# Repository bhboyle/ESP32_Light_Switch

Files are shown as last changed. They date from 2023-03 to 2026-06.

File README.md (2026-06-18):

## Ideas
I was thinking it might be a good idea to add the ability to backup and restore configurations. I hope to not have to replace these devices often but if you do have to it would be nice to have a backup of the configuration and just restore that to a new device. So I think I will make this the next feature I add to the firmware.

I have added the ability to export the switches configuration. Please note, the passwords like wifi and MQTT passwords are in plain text. This is not a problem for me but you may be concerned about this. I may work on encrypting them in the future but for now they will be in plain text. The import of the config file still needs to be coded.

## Issues
I have now ordered version three of the power board. It uses a CSE7759 energy metering chip that uses a 1 milli-ohm shunt resistor to measure the current flowing through the switch. I will have to modify the current monitoring code fairly heavily for the new energy metering to work. More to come... 

Version 3 of the power board DOES NOT WORK. Well more accurately the energy metering does not work. Do not use it. It blows components all over the place. Now on to version 4...

Almost done version 4 of the power board. I will be ordering them shortly and test them.

## Introduction
This project is an open source ESP32 based Wifi MQTT light switch. The device fits into a "Decor" style switch box. Sonoff devices are interesting but they do not fit into a regular box along side other non-smart switches.

I have gone through the first iteration of the design that does not include current sensing on the output. This version would work fine as a single on off switch but I would like this switch design to work for both single on/off switches and for three way switches as well. This requires current sensing that will be explained later.

## Objective
My objective for this project was explained at a high level in the introduction section but that does not explain my motivation for this project. Several years ago I had installed several TP-link smart switches in my home. All within a month of each other. Five years later they all died within a month of each other. That seemed like too much of a coincidence to me so I decided to make my own. This project is the idea come to life.

## Features
I will use an integrated web server for manage the following features
 * Web based control of the switch
 * Web based status of switch
 * Web based OTA updates of the switch firmware
 * Web based settings update
 * Stand alone AP mode for initial configuration
 * Remember power state for power failures using preferences lib
 * LED colors. Red = Boot up, Yellow = WIFI connected, Green = WIFI and MQTT connected, Blue = AP is active.
 * Fits into a standard wall box in North America as a Decor style switch
 * 3D models for 3D printing the housing for the parts
 * Links to the schematic and PCB designs for easy board ordering
 * LED Indication of relay status. "Breathing" LED means relay is off. Solid LED means Relay is on.
 * MQTT control of the switch
 * MQTT status of switch

## Design
At the heart of the project are two custom designed PCBs. There is a power board that handles the SPDT relay for AC switching, the conversion of the AC in to DC and provides both 5 volts DC and 3.3 volts DC to the controller board. The controller board has the ESP32 for control, communications and the buttons for triggering. There is a "light" button and a "factory" button. The light button is of course used to turn the light on and off while the factory button is used to do a factory reset. There is a Neopixel on the control board to indicate the status of the device in addition to a dedicated power led. [Here is a link](https://oshwlab.com/bhboyle/esp32-light-switch) to the EasyEDA project. This link will give you access to the schematics and board layouts. From there you can directly order boards from JLCPCB.

For safety and simplicity sake, I used the [Mean Well IRM-02-5](https://www.digikey.ca/en/products/detail/mean-well-usa-inc/IRM-02-5/7704628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) 2 watt AC-DC converter. As with most things it is a compromise. In this case between simplicity, size, safety and cost. It is a little on the pricy side at $10 USD each but it makes it very simple to build the power supply and because it is a sealed housing it is nice and safe. This module creates 5 volts DC that drives the relay and the Neopixel. In addition to the 5V power supply, I use an LDO linear regulator to generate the 3.3 volts the ESP32 needs to operate.

### The PCBs
I have designed the boards in EasyEDA. Because if this ordering from JLCPCB is very easy. I have JLCPCB populate the boards. For the power/switching board I have them populate the back of the board which is all SMB components. the front side of the board has the power supply, relay, power connection terminals and the current monitor. They all have to be manually soldered. There are also a few discrete SMB components that have to be manually soldered. The control board I ordered fully populated except for the board to board connector because I prefer to manually solder it myself. 

In order to use this as a three way switch and have the device be aware of whether or not the lighting circuit is live or not you need to measure the current flowing through the lighting circuit. This is required because it is possible, in a three way circuit for the circuit to be live without the SPDT relay being engaged due to the nature of three way circuits. Anyone who has used an three light switch knows that the two switches can end up in any position. Because of this, I use a Hall effect current sensor to determine if the lighting circuit is live or not. This has the added benefit of being able to determine how much power the circuit is using over time. Code for this part of the project is still being worked on.

I have updated the power supply board to include a LC filter on the 3.3 volt line. I have not tested this yet and it yet but it is a standard LC filter and I used a LC simulator to get near -80DB on all noise so it should work just fine. I have included an indicator to the schematic if you want to remove the filter from the circuit.

## Programming
Programming the device the first time has to be done via the USB C connector before the device is assembled. Once the initial programming is done the device can be programmed via the web interface by going to the following URL: http://deviceIp/update From here you can upload the firmware generated from platformIO.

## Todo
* The biggest remaining item on the list of things to do at this point is documentation and code optimization. 

### Parts List
[Here is a file](https://docs.google.com/spreadsheets/d/1vnkWm73apcbOtNqYmAgQMh_5zk3PtoovNklXcG1IaSc/edit?usp=sharing) that has links to the most of the harder to find parts or just parts that you have to solder yourself. 

### Software Build environment
Just in case it is not obvious, I wanted to mention that the project is being worked on in VScode with the PlatformIO plugin. If you choose to compile the code in the Arduino IDE you simply need to get the main.cpp file from the SRC folder and put it in to your sketch folder. You will also need to gather and install the needed libraries.

### DISCLAMER
Please understand that this project uses mains power and if you do not know what you're doing you can seriously harm or even kill yourself. In some places you may not even be legally allowed to install electrical equipment if you are not a licensed electrician. PLEASE be careful and if you are not confident do not do electrical work yourself. **You have been warned**

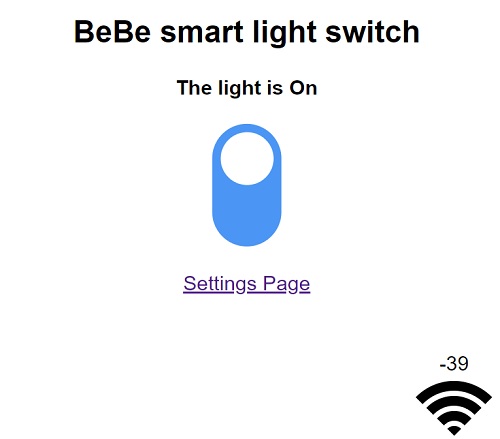
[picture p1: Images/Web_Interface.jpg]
web Image
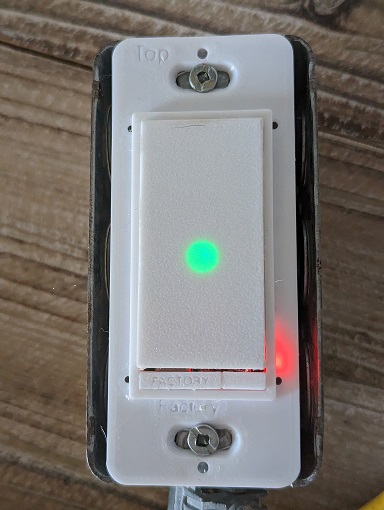
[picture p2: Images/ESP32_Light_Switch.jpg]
first image
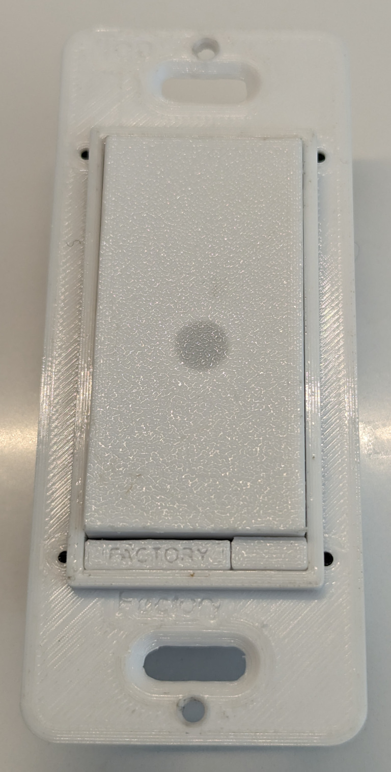
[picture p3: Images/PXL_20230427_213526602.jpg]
Second image
  
## Problems
Still having issues with the power on detection for three way mode. I have looked it how Sonoff devices do this but I dont think that will work for me here. If you have ideas how to do this please let me know.

## Ideas
I was thinking it might be a good idea to add the ability to backup and restore configurations. I hope to not have to replace these devices often but if you do have to it would be nice to have a backup of the configuration and just restore that to a new device. So I think I will make this the next feature I add to the firmware.

I have added the ability to export the switches configuration. Please note, the passwords like wifi and MQTT passwords are in plain text. This is not a problem for me but you may be concerned about this. I may work on encrypting them in the future but for now they will be in plain text. The import of the config file still needs to be coded.

## Issues
I have now ordered version three of the power board. It uses a CSE7759 energy metering chip that uses a 1 milli-ohm shunt resistor to measure the current flowing through the switch. I will have to modify the current monitoring code fairly heavily for the new energy metering to work. More to come... 

Version 3 of the power board DOES NOT WORK. Well more accurately the energy metering does not work. Do not use it. It blows components all over the place. Now on to version 4...

Almost done version 4 of the power board. I will be ordering them shortly and test them.

## Introduction
This project is an open source ESP32 based Wifi MQTT light switch. The device fits into a "Decor" style switch box. Sonoff devices are interesting but they do not fit into a regular box along side other non-smart switches.

I have gone through the first iteration of the design that does not include current sensing on the output. This version would work fine as a single on off switch but I would like this switch design to work for both single on/off switches and for three way switches as well. This requires current sensing that will be explained later.

## Objective
My objective for this project was explained at a high level in the introduction section but that does not explain my motivation for this project. Several years ago I had installed several TP-link smart switches in my home. All within a month of each other. Five years later they all died within a month of each other. That seemed like too much of a coincidence to me so I decided to make my own. This project is the idea come to life.

## Features
I will use an integrated web server for manage the following features
 * Web based control of the switch
 * Web based status of switch
 * Web based OTA updates of the switch firmware
 * Web based settings update
 * Stand alone AP mode for initial configuration
 * Remember power state for power failures using preferences lib
 * LED colors. Red = Boot up, Yellow = WIFI connected, Green = WIFI and MQTT connected, Blue = AP is active.
 * Fits into a standard wall box in North America as a Decor style switch
 * 3D models for 3D printing the housing for the parts
 * Links to the schematic and PCB designs for easy board ordering
 * LED Indication of relay status. "Breathing" LED means relay is off. Solid LED means Relay is on.
 * MQTT control of the switch
 * MQTT status of switch

## Design
At the heart of the project are two custom designed PCBs. There is a power board that handles the SPDT relay for AC switching, the conversion of the AC in to DC and provides both 5 volts DC and 3.3 volts DC to the controller board. The controller board has the ESP32 for control, communications and the buttons for triggering. There is a "light" button and a "factory" button. The light button is of course used to turn the light on and off while the factory button is used to do a factory reset. There is a Neopixel on the control board to indicate the status of the device in addition to a dedicated power led. [Here is a link](https://oshwlab.com/bhboyle/esp32-light-switch) to the EasyEDA project. This link will give you access to the schematics and board layouts. From there you can directly order boards from JLCPCB.

For safety and simplicity sake, I used the [Mean Well IRM-02-5](https://www.digikey.ca/en/products/detail/mean-well-usa-inc/IRM-02-5/7704628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) 2 watt AC-DC converter. As with most things it is a compromise. In this case between simplicity, size, safety and cost. It is a little on the pricy side at $10 USD each but it makes it very simple to build the power supply and because it is a sealed housing it is nice and safe. This module creates 5 volts DC that drives the relay and the Neopixel. In addition to the 5V power supply, I use an LDO linear regulator to generate the 3.3 volts the ESP32 needs to operate.

### The PCBs
I have designed the boards in EasyEDA. Because if this ordering from JLCPCB is very easy. I have JLCPCB populate the boards. For the power/switching board I have them populate the back of the board which is all SMB components. the front side of the board has the power supply, relay, power connection terminals and the current monitor. They all have to be manually soldered. There are also a few discrete SMB components that have to be manually soldered. The control board I ordered fully populated except for the board to board connector because I prefer to manually solder it myself. 

In order to use this as a three way switch and have the device be aware of whether or not the lighting circuit is live or not you need to measure the current flowing through the lighting circuit. This is required because it is possible, in a three way circuit for the circuit to be live without the SPDT relay being engaged due to the nature of three way circuits. Anyone who has used an three light switch knows that the two switches can end up in any position. Because of this, I use a Hall effect current sensor to determine if the lighting circuit is live or not. This has the added benefit of being able to determine how much power the circuit is using over time. Code for this part of the project is still being worked on.

I have updated the power supply board to include a LC filter on the 3.3 volt line. I have not tested this yet and it yet but it is a standard LC filter and I used a LC simulator to get near -80DB on all noise so it should work just fine. I have included an indicator to the schematic if you want to remove the filter from the circuit.

## Programming
Programming the device the first time has to be done via the USB C connector before the device is assembled. Once the initial programming is done the device can be programmed via the web interface by going to the following URL: http://deviceIp/update From here you can upload the firmware generated from platformIO.

## Todo
* The biggest remaining item on the list of things to do at this point is documentation and code optimization. 

### Parts List
[Here is a file](https://docs.google.com/spreadsheets/d/1vnkWm73apcbOtNqYmAgQMh_5zk3PtoovNklXcG1IaSc/edit?usp=sharing) that has links to the most of the harder to find parts or just parts that you have to solder yourself. 

### Software Build environment
Just in case it is not obvious, I wanted to mention that the project is being worked on in VScode with the PlatformIO plugin. If you choose to compile the code in the Arduino IDE you simply need to get the main.cpp file from the SRC folder and put it in to your sketch folder. You will also need to gather and install the needed libraries.

### DISCLAMER
Please understand that this project uses mains power and if you do not know what you're doing you can seriously harm or even kill yourself. In some places you may not even be legally allowed to install electrical equipment if you are not a licensed electrician. PLEASE be careful and if you are not confident do not do electrical work yourself. **You have been warned**

web Image first image Second image

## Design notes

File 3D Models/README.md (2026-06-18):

# Using the file

The file here is a Fusion 360 file. You will need to install and activate Fusion 360 to work with the model. 

The one file contains all of the individual bodies for the first version of the housing and buttons. I usually hide the item that I don't want to print and then use Fusion to send the file to Cura for 3D printing.

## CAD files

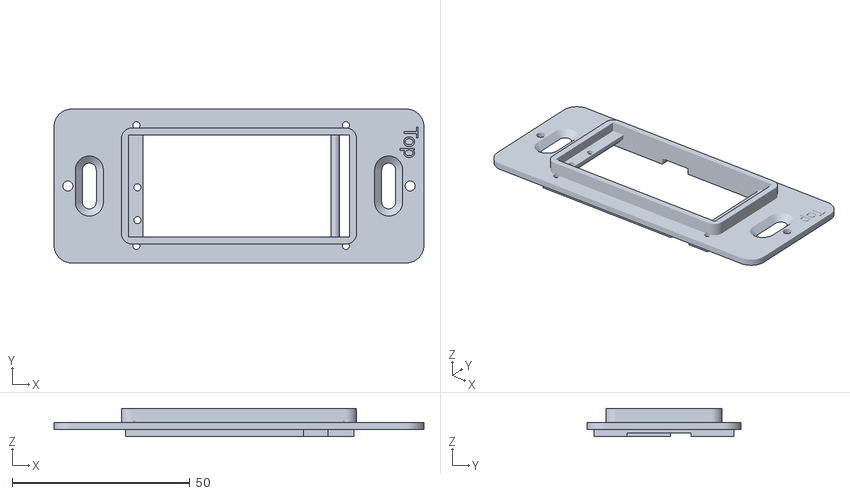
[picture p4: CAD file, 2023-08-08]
3D Models/V2 Face plate.stl
104.2 x 43.4 x 8.00

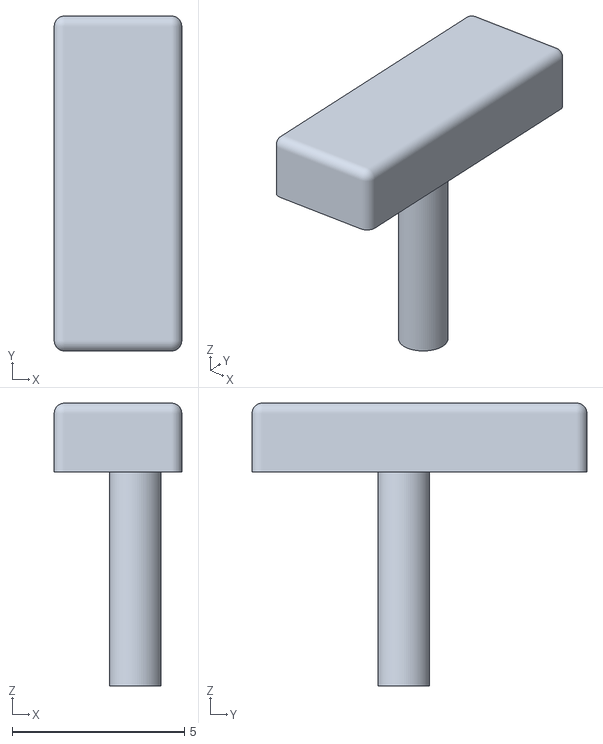
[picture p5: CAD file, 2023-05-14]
3D Models/V2 Reset Button.stl
3.70 x 9.71 x 8.20

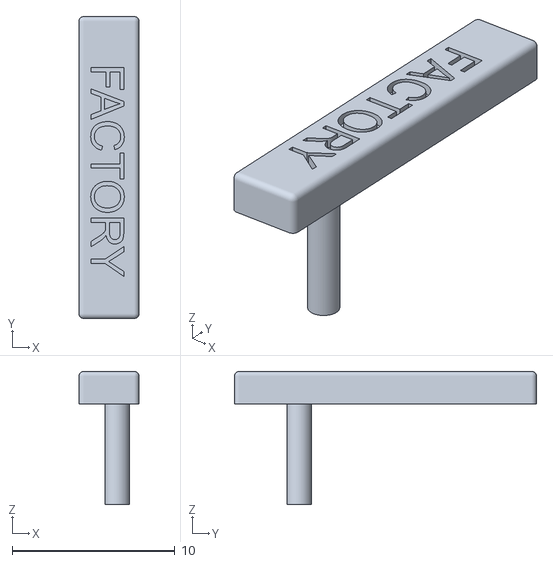
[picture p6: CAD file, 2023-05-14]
3D Models/V2 Factory Button.stl
3.70 x 18.6 x 8.20

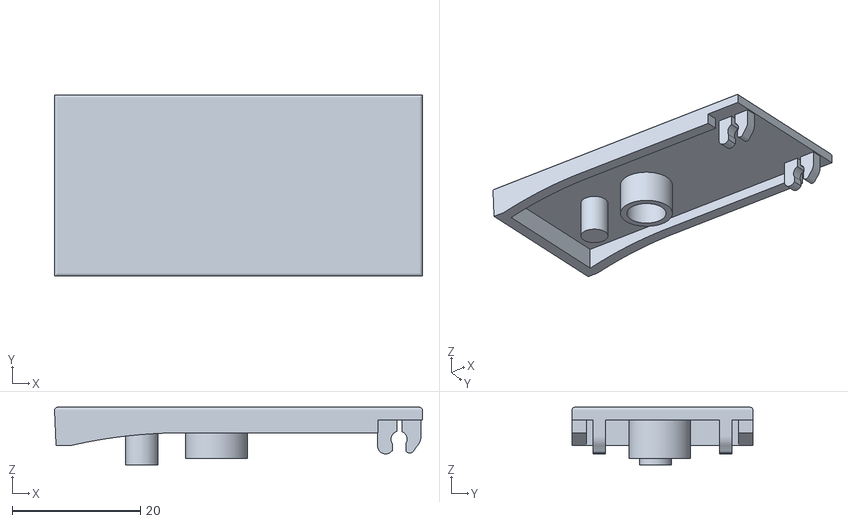
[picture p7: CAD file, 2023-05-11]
3D Models/V2 Light Button.stl
57.4 x 28.3 x 9.00

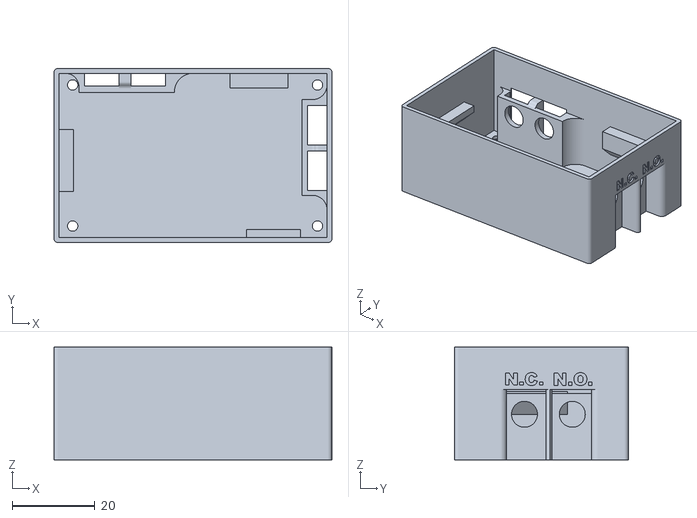
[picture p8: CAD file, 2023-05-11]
3D Models/V2 Lower Housing.stl
67.0 x 42.0 x 27.2

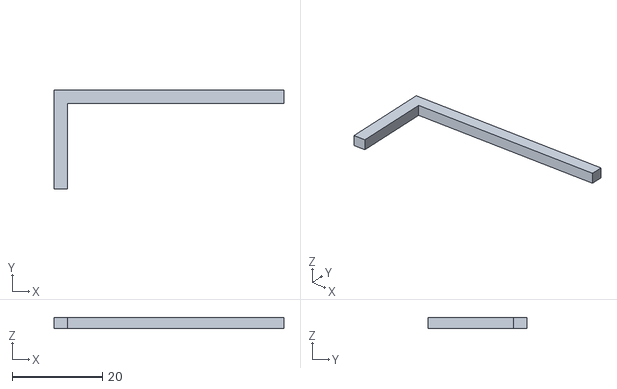
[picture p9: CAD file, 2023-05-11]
3D Models/V 2Spacer.stl
51.0 x 22.0 x 2.50

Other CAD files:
3D Models/ESP32 Light switch housing v41.f3d
3D Models/Left middle front corner.f3d

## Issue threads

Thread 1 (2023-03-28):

Need to add code to handle power monitoring

bhboyle, 2023-03-28:
I have added the ACS712 to the design. I need to add code to check if there is current andif there is then 1. report that, 2. log it power usage

bhboyle, 2023-04-03:
Code is in place but I need to get the updated boards to test the code

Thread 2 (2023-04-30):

Quiescent power draw

brusshamilton, 2023-04-30:
It looks like the quiescent power usage is around 2W for this design. Given modern lightbulbs use ~9W, that seems like a lot to devote to a switch.

Fortunately, I think there are some things we can optimize with this design.

The processor should probably be put into a low power mode between requests. That may be a bit difficult with WIFI. I'd have to check the datasheet in detail to so how much we can save here.

The hall effect sensor is a real power hog though. Have you considered making it so it can be disabled and enabled? We don't need to measure that all the time, so we should disable it when it's not in use.

Using an linear regulator to step down from 5V to 3.3V almost doubles the quiescent power usage. If we could get rid of the 5V requirement then that would be ideal. Otherwise we might want to bite the bullet and get a buck converter -- the 240mA draw from the ESP32 is not cheap.

bhboyle, 2023-04-30:
Hi. Thanks for taking the time to comment.

Given that the relay and the current montor are rated for 10 amps at 120 volts, that is 1200 watts of capacity. 2 watts in that scope is negligable. Also since my objective with this project was to have an ESP32 powered wifi based decor style light switch, I had to account for the highest power that the ESP32 and the rest of the circuit would need when selecting the power supply. My electronics class teacher always said that you should always supply double the curcuits power requierments. With that in mind I did not do as my teacher suggested in this case as the power supply does not provide 2*250ma plus the 90 ma the relay requires plus the other parts.

I feel that I made a decent comprmise on power supply versus power needs. Regardless of that there is always room for improvement but I am not willing to give up the ESP32 and the relay and just those two compoents use around 200ma or 2 watts at full power draw.

I could think about powering down the current sensor however the typical current draw is 8.5ma. This is less than the LED so I dont feel that it is worth considering.

Cheers.

brusshamilton, 2023-05-01:
That's interesting. I thought this was for a light switch so I did not consider that it might be asked to draw a full 10 amp load. Also, I guess my only experience with the Hall effect sensors is with small battery powered devices which have tighter power margins, so it doesn't seem to be a problem here. The relay is also only drawing the current when the switch is on (which I wouldn't consider quiescent) and only takes 200mW (based on the datasheet I pulled up for HF33F).

But you can still reduce the power usage if you can get rid of the 5V power rail. I thought you might need it for the relay, but the relay seems to support voltages that low. With a linear power regulator you're paying for the power at the higher voltage even if you only need the lower voltage. That's fine if you are not pulling much current, but at 250mA, going from 5V to 3.3V wastes 425mW as heat, compared to the 825mW that's performing useful work. I didn't see anywhere where you needed 5V other than USB, which can provide it's own 5V power. It should be safe to let that float at 3.3V when the 5V is not connected (for debugging/programming).

Also most IoT and other embedded devices take significant advantage of sleeping during idle times to reduce power usage (and heat generation, which can fatigue and prematurely age components).

As for the power supply margin, I think doubling might be useful for students, but typically I wouldn't overspec by more than 30%. You have the appropriate decoupling capacitors in the right places, so I'm not that concerned with power noise. Though as with all high frequency circuits you would want to check and if it is a problem see if you can run the system at 3.5 with a linear regulator down to 3.3 V for extra stability.

bhboyle, 2023-05-02:
The Neopixel and the relay both run on 5V. I had originally planned to use a 3.3v power supply and had looked at running the relay at 3.3v but once I decided to incorperate the Neopixel I went with the 5V and 3.3. LDO reg. I did a lot if bench testing the ESP32 and other 3.3v components and found that the ESP32 rarely drew more than around 80-100ma and when it did it was not for very long. With that said the current draw on the 3.3v reg averages around 100ma and the regulator never even get much more than warm. I would think the temp rise above ambiant is around the 5 degrees C range. someting I was very comfortable. If it was any more than that I would have redesign the power section.

I do see that what you mean about power saving modes for the ESP32 howver since I want the web page and the MQTT client active at all times I dont see how that could work in my use case.

Cheers.

Closed 2023-05-10.

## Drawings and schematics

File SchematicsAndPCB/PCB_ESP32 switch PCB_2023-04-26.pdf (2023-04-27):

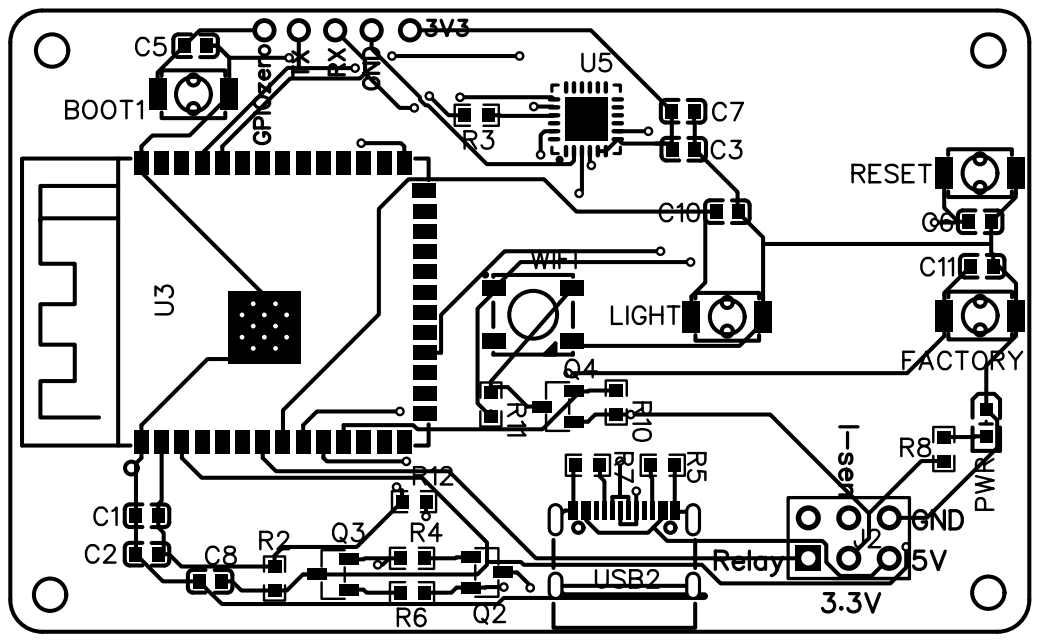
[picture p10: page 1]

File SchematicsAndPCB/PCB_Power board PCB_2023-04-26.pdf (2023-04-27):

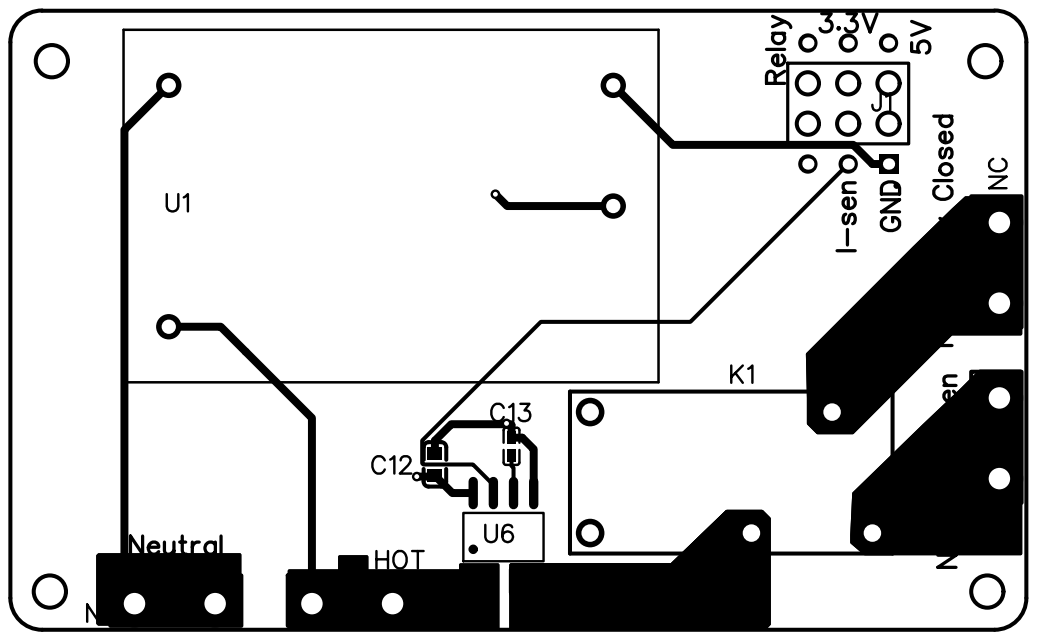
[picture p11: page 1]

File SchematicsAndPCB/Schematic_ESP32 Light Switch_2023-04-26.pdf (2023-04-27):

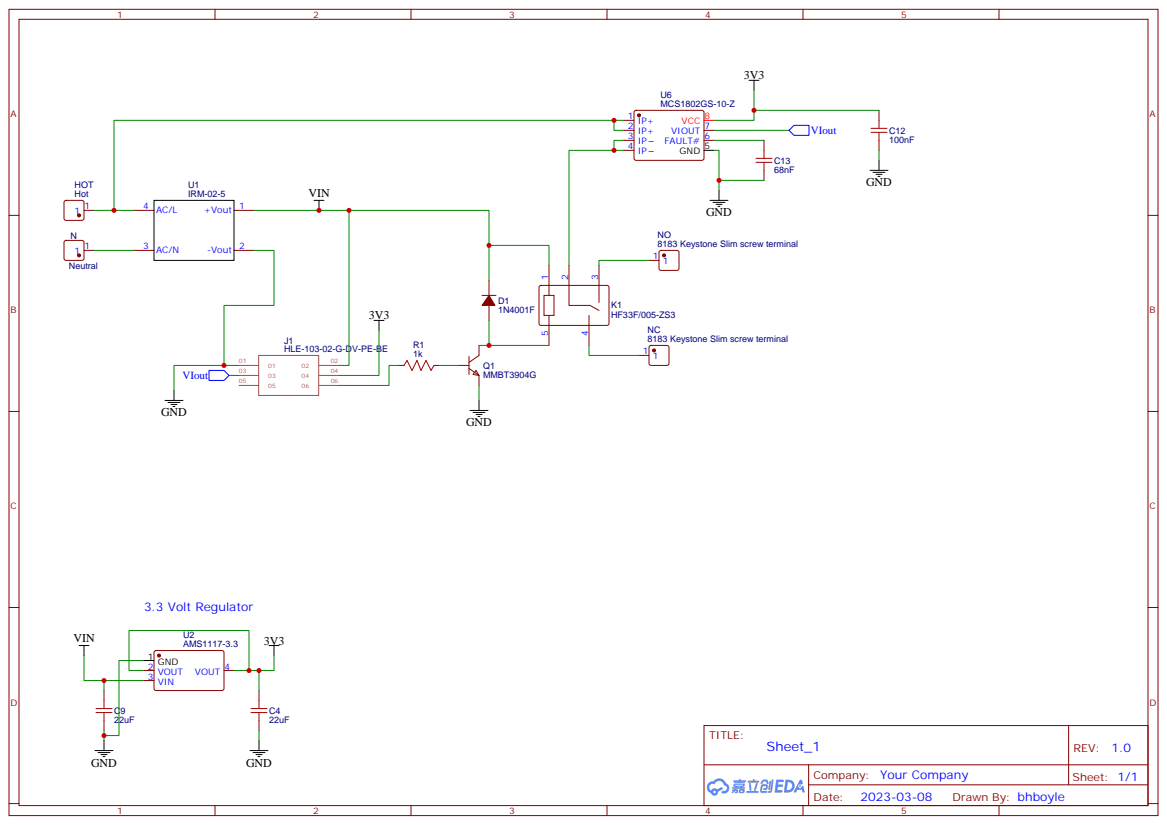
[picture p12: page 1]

HLE-103-02-G-DV-PE-BE

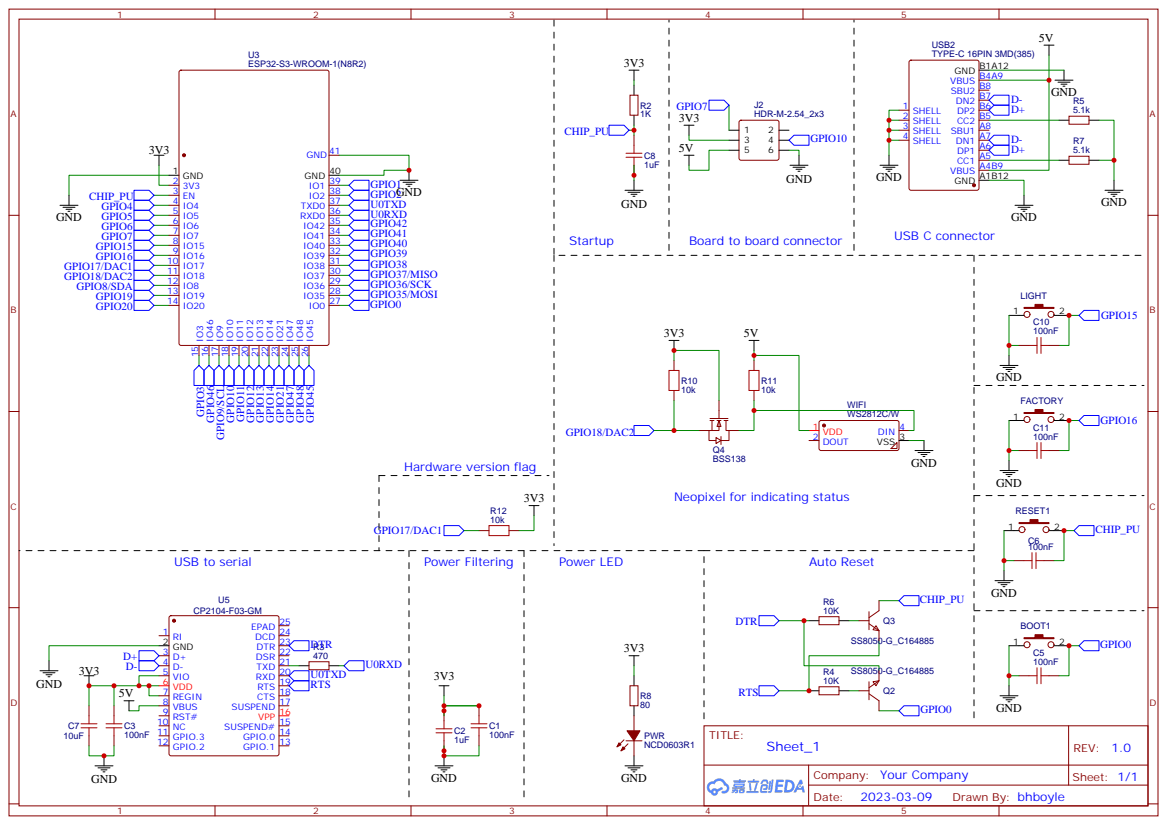
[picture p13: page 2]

IO0 27 IO⁴⁵ 26 IO⁴⁸ 25 IO⁴⁷ 24 IO²¹ 23 IO¹⁴ 22 IO¹³ 21 IO¹² 20 IO¹¹ 19 IO¹⁰ 18 IO⁹ 17 IO⁴⁶ 16 IO³ 15

Neopixel for indicating status

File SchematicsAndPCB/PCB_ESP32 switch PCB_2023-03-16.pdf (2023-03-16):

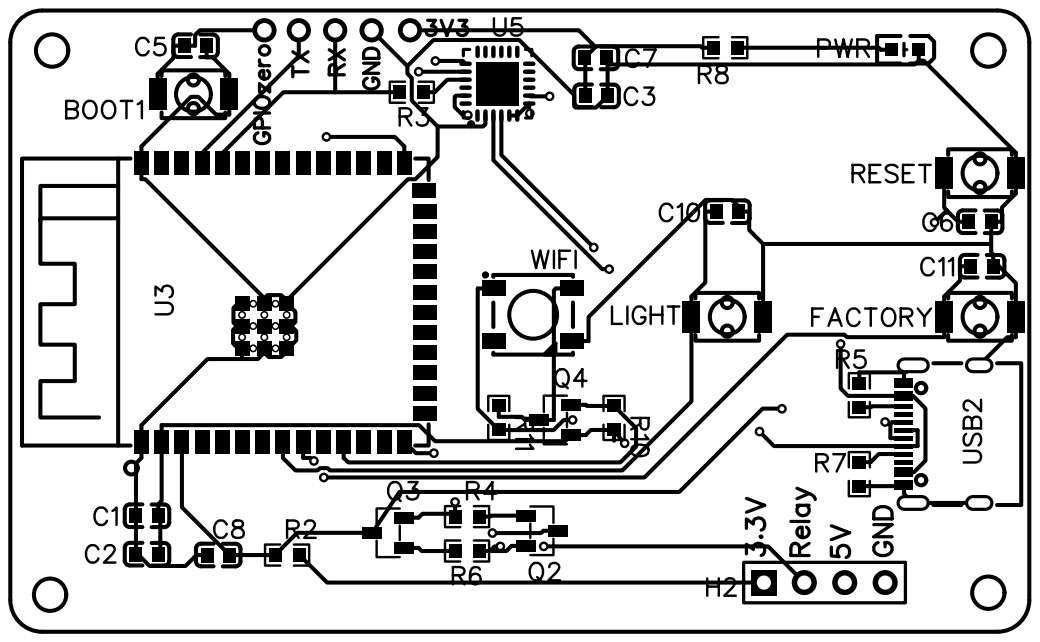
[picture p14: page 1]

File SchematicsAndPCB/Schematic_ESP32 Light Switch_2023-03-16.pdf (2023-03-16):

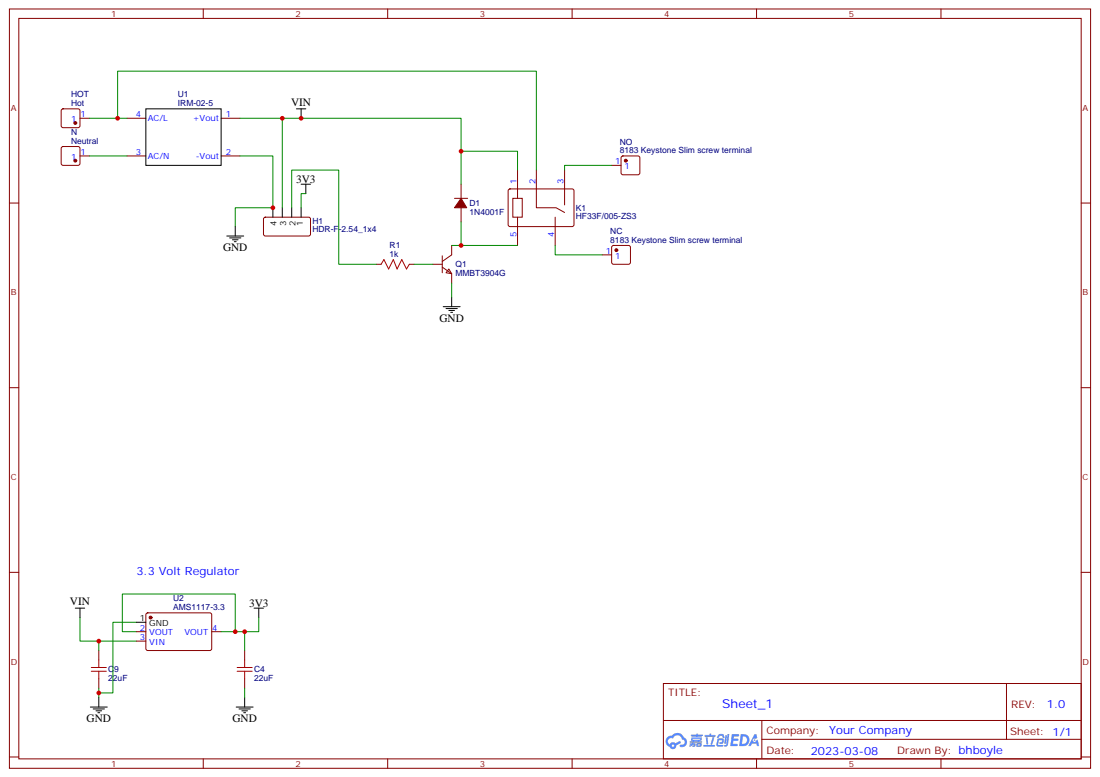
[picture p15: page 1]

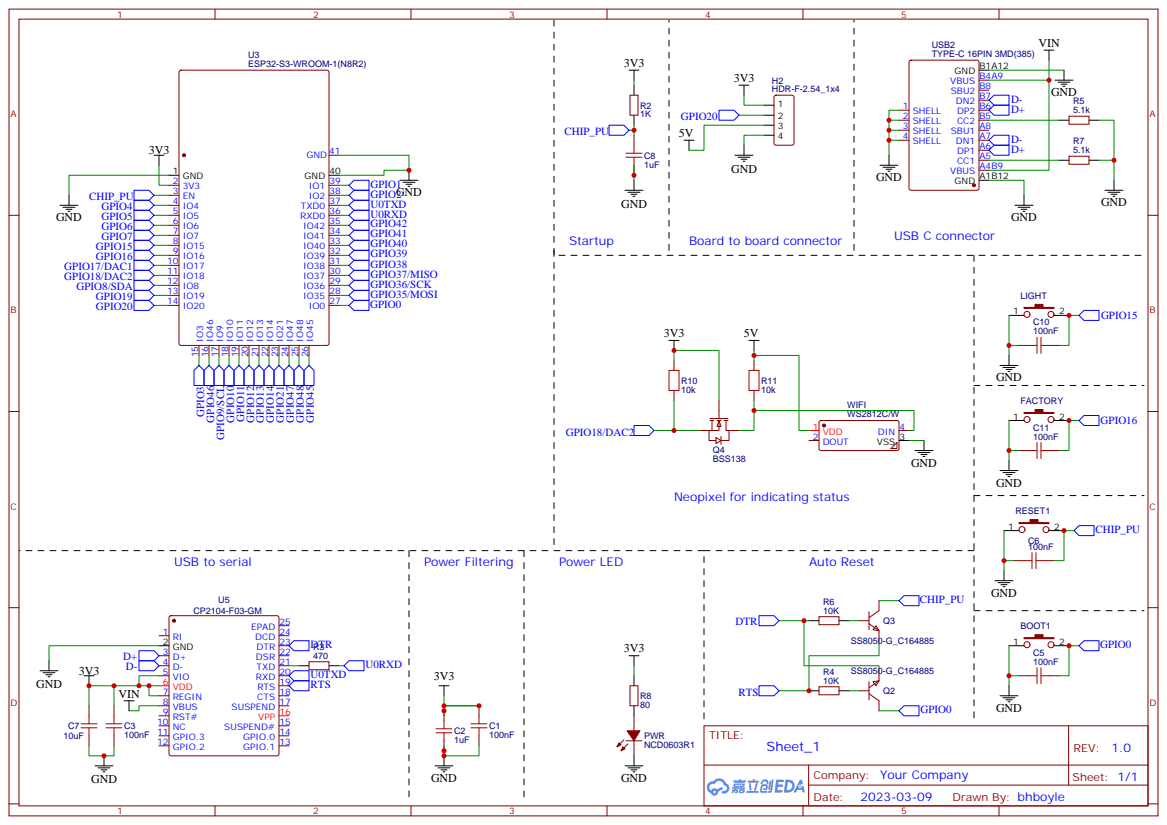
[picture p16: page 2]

IO0 27 IO⁴⁵ 26 IO⁴⁸ 25 IO⁴⁷ 24 IO²¹ 23 IO¹⁴ 22 IO¹³ 21 IO¹² 20 IO¹¹ 19 IO¹⁰ 18 IO⁹ 17 IO⁴⁶ 16 IO³ 15

Neopixel for indicating status

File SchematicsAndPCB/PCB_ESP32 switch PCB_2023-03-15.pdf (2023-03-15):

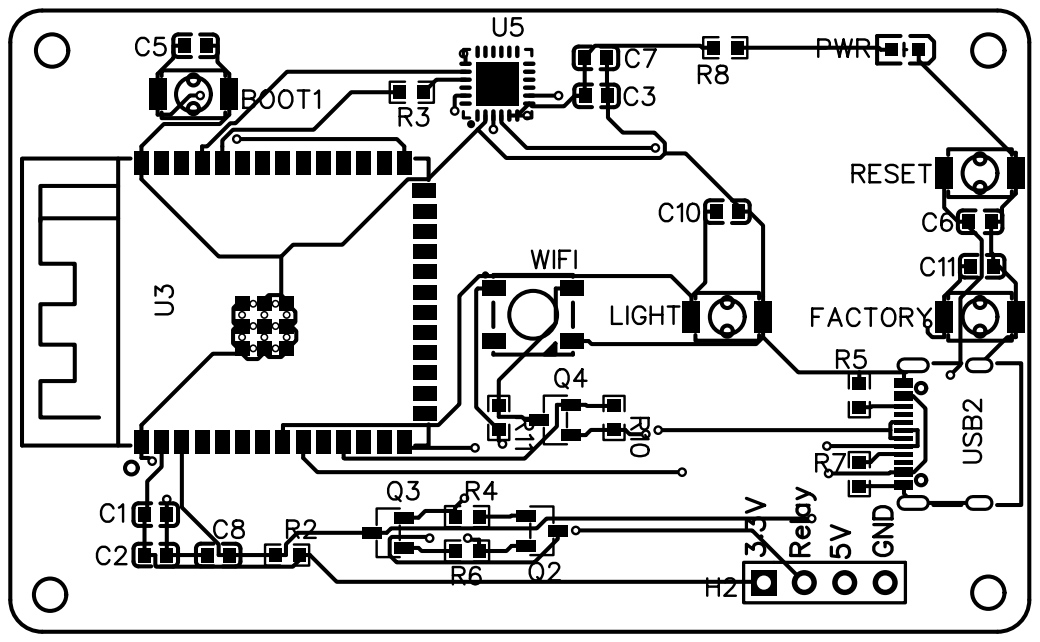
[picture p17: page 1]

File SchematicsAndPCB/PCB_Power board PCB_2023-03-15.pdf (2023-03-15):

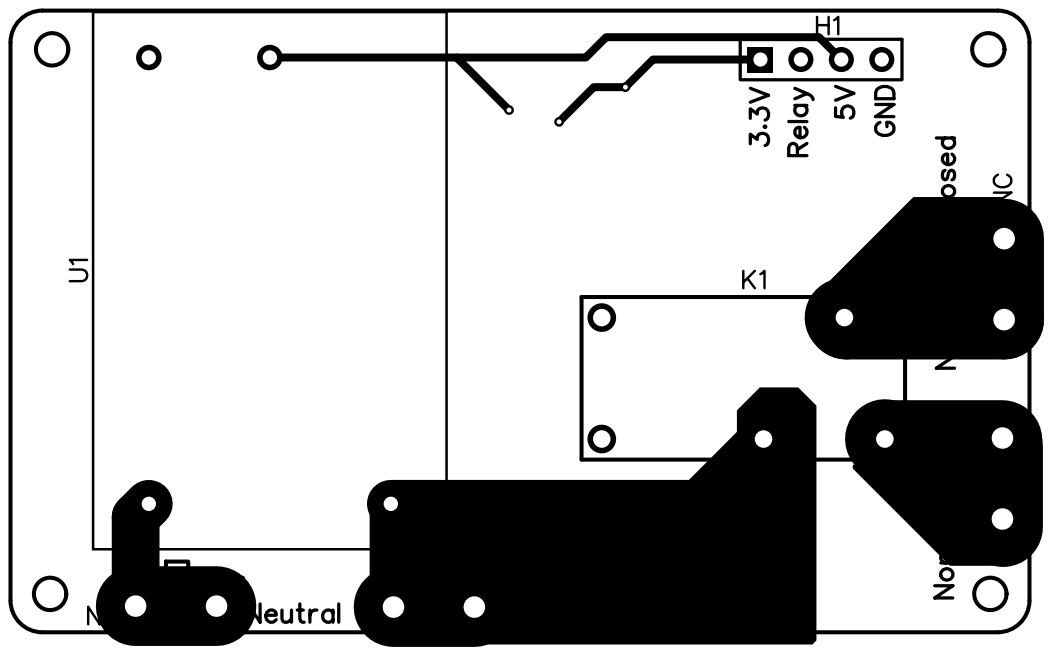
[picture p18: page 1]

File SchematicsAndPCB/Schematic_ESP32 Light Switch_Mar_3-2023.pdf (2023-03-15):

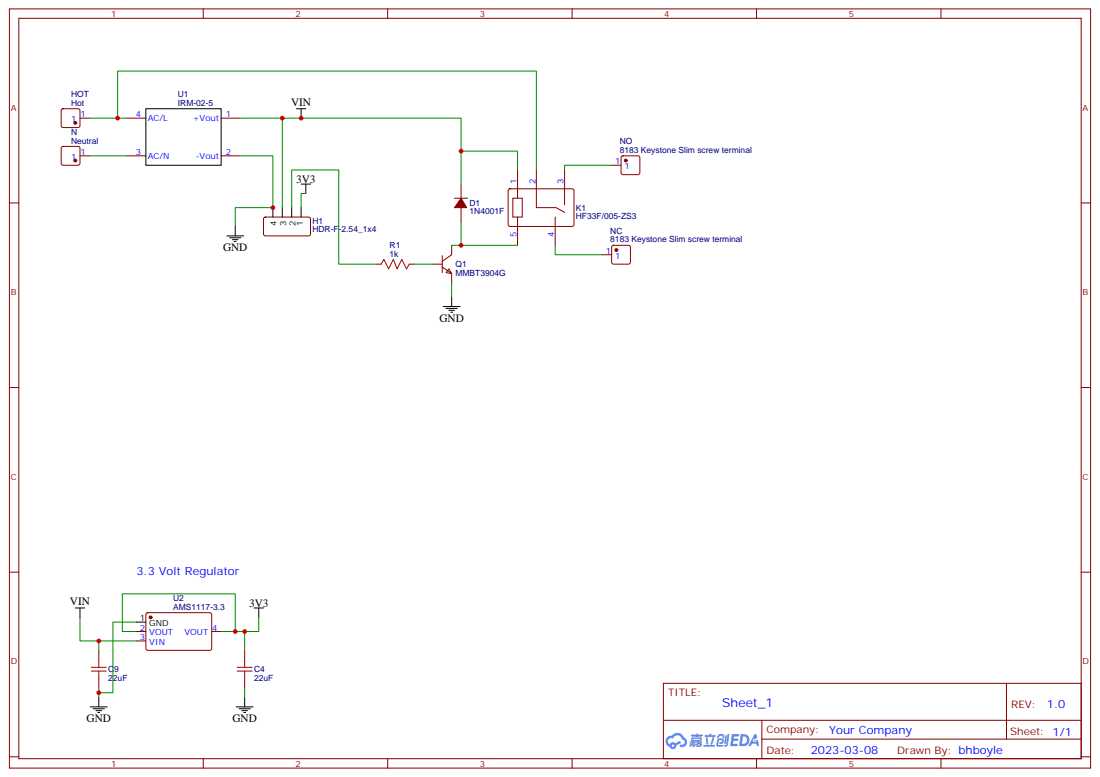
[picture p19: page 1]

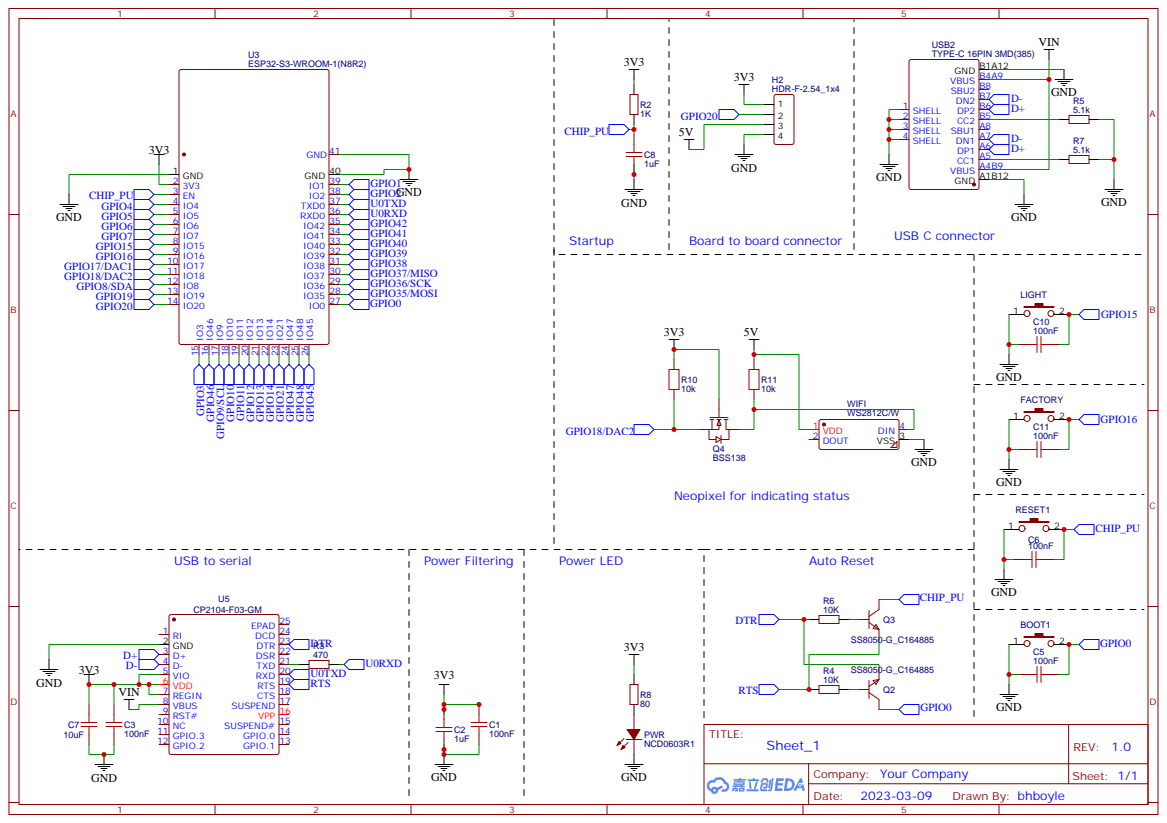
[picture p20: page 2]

IO0 27 IO⁴⁵ 26 IO⁴⁸ 25 IO⁴⁷ 24 IO²¹ 23 IO¹⁴ 22 IO¹³ 21 IO¹² 20 IO¹¹ 19 IO¹⁰ 18 IO⁹ 17 IO⁴⁶ 16 IO³ 15

Neopixel for indicating status

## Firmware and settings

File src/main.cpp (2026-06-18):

#include <Arduino.h>
#include <WiFi.h>
#include <Preferences.h>
#include <Adafruit_NeoPixel.h>
#include <MQTT.h>
#include <AsyncTCP.h>
#include <ESPAsyncWebServer.h>
#include <nvs_flash.h>
#include <ArduinoJson.h>
#include <AsyncElegantOTA.h>
#include "HTML.h"
#include <time.h>
#include "esp_sntp.h"
#include <regex>
#include <HTTPClient.h>

#define NeoPixelPin 18
#define NUMPIXELS 1

#define MY_NTP_SERVER "pool.ntp.org"
#define MY_TZ "EST5EDT,M3.2.0,M11.1.0"
#define VersionControlFlag 17 // the pin to check to see if it is hardware version 2
#define Version1 20           // the pin the relay is on in hardware version 1
#define Version2 7            // the pin the relay is on in hardware version 2
#define BreathDelay 2         // how long to wait before starting the next stage int the LED breath
#define ResetTime 10000        // how many milliseconds to wait before doing factory reset
#define LightButton 15        // The input pin of the button that triggers the relay
#define FactoryReset 16       // The input pin of the button that will trigger a factory reset

// #define debug

// variables

int RelayPin;          // The output pin that will trigger the relay
//                               0 ,    1      ,  2  ,         3   ,       4   ,         5   ,           6,      7      ,      8,              9,...............
String variablesArray[13] = {"ssid", "password", "HostName", "MQTTIP", "UserName", "Password", "PublishTopic", "SubTopic", "RelayState", "LEDBrightness", "ThreeWayMode", "ThreeWayRole", "PartnerIP"};
String valuesArray[13] = {"", "", "", "", "", "", "", "", "", "", "", "", ""};
int totalVariables = 13;
String index_html_AP = "";            // String that will hold the web page code if the switch is not configured
String settingsHTML = "";             // String that will hold the settings web page code of a configured switch
const char *ssidAP = "BeBe-Light";    // Access point SSID if the switch is not configured
const char *passwordAP = "12345678";  // Access point password if the switch is not configured
IPAddress local_ipAP(192, 168, 1, 1); // Access point IP, Netmask and gateway settings  if not configured
IPAddress gatewayAP(192, 168, 1, 1);
IPAddress subnetAP(255, 255, 255, 0);
bool WifiAPStatus = false; // used to track if in access point mode or not and if not then connect to the configured network
bool relayStatus = 0;      // used to hold the status of the relay
char ssid[33];             // SSID variable for connecting to the configured network (32 + null terminator)
char ssidPassword[64];     // SSID password for connecting to the configured network
char Hostname[32];         // The hostname of the device used for the DNS settings and the MQTT server
IPAddress MQTTserver; // address of the MQTT server
char MQTTuser[32];    // username for connecting to the MQTT server
char MQTTpass[64];    // Password for connecting to the MQTT server
char PublishTopic[128]; // The MQTT topic that the device will publish to with the status of the relay or other things.
char SubTopic[128];     // MQTT topic that we will subscribe to for triggering
bool allSet = false; // used for checking the web page
int inputError = -1; // used during processing if input fields on the configuration web page
unsigned long button_press_time = 0;   // used to debouncing the buttons
unsigned long button_release_time = 0; // also used for debouncing the buttons
const char *PARAM_INPUT = "value";     // used to handle the slider that sets the LED brightness on the settings webpage of configured switches
const char *PARAM_INPUT_1 = "state";   // used to manage the data that is sent to the ESP32 during configuration
bool MQTTinfoFlag = 0;                 // used because you can not send an MQTT message in the call back. This flag is turned on then we send a message in the loop
int lightButtonState = 0;                  // used for making sure the light button is only pressed once for each press and release
time_t now;                      // this is the epoch
tm tm;                           // the structure tm holds time information in a more convenient way
unsigned long lastTimeCheck = 0; // The last time we updated the time variables
String sliderValue = "0";        // used to update the LED brightness value
bool LEDBreathDirection = 0;     // variable use for tracking if the LED is getting brighter or darker
unsigned long LEDLastTime;       // Used for keeping track of when the LED was last updated
int LEDBrightness = 0;           // This is the variable that holds the LED brightness value
bool configured = false;         // used to track if the switch is configured or not.
bool threeWayMode = false;       // Whether three-way sync mode is enabled
String threeWayRole = "";        // "primary" or "secondary"
String partnerIP = "";           // IP address of the partner switch
bool lightState = false;         // Tracks whether the light is actually ON or OFF

// This raw string is used to define the CSS styling for both versions of the configuration pages. Changes here will affect both pages.
String Style_HTML = R"---*(<style> 
input, textarea {border:3; padding:3px; border-radius: 8px 16px } 
input:focus { outline: none !important; border:3px solid OrangeRed; box-shadow: rgba(0, 0, 0, 0.3) 0px 8px 8px, rgba(0, 0, 0, 0.22) 0px 8px 8px; } 
</style>)---*";

// Object constructors
WiFiClient wifiClient; // create the wifi object
MQTTClient client;     // create the MQTT client object
Adafruit_NeoPixel pixels(NUMPIXELS, NeoPixelPin, NEO_GRB + NEO_KHZ800); // Create the object for the single Neopixel used for status indication
Preferences preferences;                                                // Create the object that will hold and get the variables from NVram
AsyncWebServer server_AP(80);                                           // Create the web server object

// function declarations

void checkWIFI();
void maintainMQTT();
void setColor(int r, int g, int b);
void getPrefs();
String convert2String(int temp);
bool ValidateIP(String IP);
void createAP_IndexHtml();
void handleSwitch();
void handle_NotFound(AsyncWebServerRequest *request);
void doSwitch(int status);
String outputState();
String processor(const String &var);
void checkFactoryReset();
void HandleMQTTinfo();
void updateTime();
void createSettingHTML();
void handleLEDBreath();
void handleUpload(AsyncWebServerRequest *request, String filename, size_t index, uint8_t *data, size_t len, bool final);
void notifyPartner(bool newLightState);

// Start of setup function
void setup()
{

  // check to see if the version control flag is set in hardware
  pinMode(VersionControlFlag, INPUT);
  delay(10); // delay to make sure the input had settled before reading its status
  if (digitalRead(VersionControlFlag))
  {
    RelayPin = Version2; // if it is set then set the relay pin to version 2
  }
  else
  {
    RelayPin = Version1; // if not then set it to version 1
  }

  pixels.setBrightness(100); // Set BRIGHTNESS of the indicator Neopixel
  pixels.begin();            // INITIALIZE NeoPixel strip object (REQUIRED)
  pixels.clear();            // Set all pixel colors to 'off'
  setColor(255, 0, 0);       // Set LED to red at boot up

  pinMode(LightButton, INPUT_PULLUP);  // Setup the intput pin for the button that will trigger the relay
  pinMode(FactoryReset, INPUT_PULLUP); // setup the input pin for the button that will be used to reset the device to factory
  pinMode(RelayPin, OUTPUT);           // Setup the output pin for the relay

#ifdef debug
  Serial.begin(115200);
#endif

  // Boot-time factory reset.
  // The normal factory-reset check lives in loop(), but a configured device that
  // cannot reach WiFi reboots from inside getPrefs()->checkWIFI() before loop()
  // ever runs. That makes the device impossible to reset by button once it is in
  // a WiFi boot loop. So check the button here, before any WiFi logic can reboot.
  // Hold the reset button at power-up for 3 seconds to wipe the config.
  if (digitalRead(FactoryReset) == LOW)
  {
    unsigned long holdStart = millis();
    while (digitalRead(FactoryReset) == LOW)
    {
      if (millis() - holdStart > 3000)
      {
        for (int i = 0; i < 10; i++) // light show so the user knows the reset took
        {
          setColor(255, 0, 0);
          delay(150);
          setColor(0, 0, 255);
          delay(150);
        }
        nvs_flash_erase(); // wipe the NV ram (saved config)
        nvs_flash_init();
        ESP.restart(); // reboot into unconfigured AP mode
      }
    }
  }

  getPrefs();

  configTime(0, 0, MY_NTP_SERVER); // 0, 0 because we will use TZ in the next line
  setenv("TZ", MY_TZ, 1);          // Set environment variable with your time zone
  tzset();
  sntp_set_sync_interval(12 * 60 * 60 * 1000UL); // set the NTP server poll interval to every 12 hours

  LEDLastTime = millis();

} // end of setup function

// main loop function
void loop()
{

  checkWIFI();

  maintainMQTT();

  handleSwitch();

  checkFactoryReset();

  HandleMQTTinfo();

  updateTime();

  handleLEDBreath();

} // End of main loop function

/*

****** Functions begin here   ***********

*/

// This function checks if the switch button is pressed and toggles the light is it has
void handleSwitch()
{
  int temp = digitalRead(LightButton); // read the button pin

  if (temp == 0) // if the button has been pressed
  {

    if (lightButtonState == 0) // if the button pressed variable is not set do the following
    {
      relayStatus = !relayStatus; // change the relay variable
      doSwitch(relayStatus);      // change the state of the relay
      lightButtonState = 1;       // set the button pressed variable
    }
  }
  else // if the button is not pressed reset the button pressed variable. This stops debounce and stops the button from re-triggering the relay if it is held pressed
  {
    lightButtonState = 0;
  }

} // end of handleSwitch function

// This function sends an HTTP GET request to the partner switch to update its lightState
void notifyPartner(bool newLightState)
{
  if (!threeWayMode || partnerIP.length() == 0)
    return;

  HTTPClient http;
  String url = "http://" + partnerIP + "/api/statechange?state=" + String(newLightState ? 1 : 0);
  http.begin(url);
  http.setTimeout(2000);
  http.GET();
  http.end();
} // end of notifyPartner function

// This function changes the relay output pin to the new state, publishes the new state
// to the MQTT server and stores the current state in NVram
void doSwitch(int status)
{
  digitalWrite(RelayPin, status);
  valuesArray[8] = String(status);
  preferences.begin("configuration", false);
  preferences.putString(variablesArray[8].c_str(), valuesArray[8]);
  preferences.end();

  if (threeWayMode)
  {
    lightState = !lightState;

    if (threeWayRole == "primary")
    {
      client.publish(valuesArray[6], String(lightState ? 1 : 0));
      notifyPartner(lightState);
    }
    else if (threeWayRole == "secondary")
    {
      notifyPartner(lightState);
    }
  }
  else
  {
    client.publish(valuesArray[6], String(status));
  }

} // end of doSwitch function

// MQTT callback function to handle any trigger events from the MQTT server
void MQTTcallBack(String topic, String payload)
{
  String tempChar = payload; // grab the payload
  if (tempChar == "0")       // check if the payload is a zero
  {
    relayStatus = 0;
    doSwitch(relayStatus);
  }
  else if (tempChar == "off")
  {
    relayStatus = 0;
    doSwitch(relayStatus);
  }
  else if (tempChar == "false")
  {
    relayStatus = 0;
    doSwitch(relayStatus);
  }
  else if (tempChar == "1") // if it is a one then turn on the light
  {
    relayStatus = 1;
    doSwitch(relayStatus);
  }
  else if (tempChar == "on")
  {
    relayStatus = 1;
    doSwitch(relayStatus);
  }
  else if (tempChar == "true")
  {
    relayStatus = 1;
    doSwitch(relayStatus);
  }
  else if (tempChar == "2") // if it is a 2 then toggle the light
  {
    relayStatus = !relayStatus;
    doSwitch(relayStatus);
  }
  else if (tempChar == "info")
  {
    MQTTinfoFlag = true;
  }
} // end of MQTTcallback function

// This function will start the WIFI connection or maintains it if it is already connected
void checkWIFI()
{

  if (WifiAPStatus == 0)
  {
    if (WiFi.status() != WL_CONNECTED)
    {

#ifdef debug
      Serial.print("Hostname = ");
      Serial.println(Hostname);
#endif

      WiFi.setHostname(Hostname);     // Set the WIFI hostname of the device
      WiFi.begin(ssid, ssidPassword); // connect to the WIFI

      delay(100);

      int count = 0; // create a variable that is used to set a timer for connecting to the WIFI
      while (WiFi.status() != WL_CONNECTED)
      {             // check if it is connected to the AP
        delay(100); // wait 100 miliseconds
        count++;    // Increment the counter variable
        if (count > 30)
        {
          break;
        } // it is had been trying to connect to the WIFI for 30 * 100 milliseconds then stop trying
      }

      // This second WIFI status is used to do indicate a failed connection and then put the ESP32 in deep sleep
      if (WiFi.status() != WL_CONNECTED)
      { // if it can not connect to the wifi
        // write the boot verion and count into eeprom and reboot

        ESP.restart();
      }
      setColor(255, 255, 0); // Set LED to Yellow
    }
  }

} // end of checkwifi function

// This function starts the MQTT connection and if it is already connected it will maintain the connection
void maintainMQTT()
{
  // Secondary switches in three-way mode do not use MQTT
  if (threeWayMode && threeWayRole == "secondary")
  {
    if (WiFi.status() == WL_CONNECTED)
    {
      setColor(0, 255, 255); // Cyan for secondary mode
    }
    return;
  }

  if (WifiAPStatus == 0)
  {
    if (client.connected()) // used to maintain the MQTT connection
    {
      client.loop();
      setColor(0, 255, 0); // Set LED to Green
    }
    else // if the connection has failed then reconnect to the MQTT server
    {
      // connect to the MQTT server
      client.begin(MQTTserver, 1883, wifiClient);
      // connect(const char clientID[], const char username[], const char password[], bool skip = false);
      client.connect(Hostname, MQTTuser, MQTTpass, false);

      // publish/subscribe
      if (client.connected())
      {
        client.publish("hello/message", "hello world");
        client.subscribe(SubTopic);
        client.onMessage(MQTTcallBack);
        setColor(0, 255, 0); // Set LED to Green
      }
    }
  }

} // end of maintainMQTT function

// This function sets the color of the NEOPixel LED. It must be called with
// an R-ed intensity, an G-reen intensity and a B-lue intensity for the Neopixel
void setColor(int r, int g, int b)
{
  pixels.setPixelColor(0, pixels.Color(r, g, b));
  pixels.show();
} // end of setColor function
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

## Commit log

2023-03-15 Switching to platformIO
2023-03-15 Adding Schematics
2023-03-15 Updating Schematics
2023-03-16 Updating Drawings and board layouts
2023-03-17 Changing the switch handling
2023-03-18 adding power supply details
2023-03-20 Adding web page for switching light on and off
2023-03-30 Fixed bug LED would turn blue for AP mode then red
    [main.cpp]
2023-03-30 Adding 3D Models
    [ESP32 Light switch Lower housing v6.f3d]
2023-04-01 Updated 3d Model for lower housing
    [ESP32 Light switch housing v8.f3d]
2023-04-01 Renaming 3D model file
    [ESP32 Light switch Lower housing v8.f3d]
2023-04-03 Adding Settings page to configured switch.
2023-04-04 Updating Settings page for configured switches
2023-04-05 Many updates
    [ESP32 Light switch housing v18.f3d]
2023-04-09 3D model mostly done
    [ESP32 Light switch housing v25.f3d]
2023-04-10 Everything fits.
    [ESP32 Light switch housing v27.f3d]
2023-04-13 Adding cancel button to settings page
2023-04-14 Adding version control to the relay pin
2023-04-24 Added Breathing LED to indicate switch state
2023-04-27 Deleting old models
    [ESP32 Light switch Lower housing v6.f3d, ESP32 Light switch Lower housing v8.f3d, ESP32 Light switch housing v18.f3d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]
2023-05-11 Updating 3D models for V2
    [ESP32 Light switch housing v27.f3d, ESP32 Light switch housing v38.f3d, V 2Spacer.stl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]
2023-05-14 Adjusting small button post length
    [V2 Factory Button.stl, V2 Reset Button.stl]
2023-05-15 Updating faceplace mounting holes
    [V2 Face plate.stl]
2023-05-15 Updated 3D Model
    [ESP32 Light switch housing v38.f3d, ESP32 Light switch housing v41.f3d]
2023-05-17 Fixed problem with configuration setup
    [main.cpp]
2023-05-20 Adding sensor noise mitigation
    [main.cpp]
2023-05-20 Adding a variable for the noiseThreshold selection
    [main.cpp]
2023-05-20 fixing logic for current sensor noise mitigation
    [main.cpp]
2023-06-05 Fixing occasional boot problems
    [main.cpp]
2023-07-26 Working on the current measurement code. Not there
2023-07-31 Initial changes for V3 of power board
2023-08-08 Several changes for the new current monitoring
    [V2 Face plate.stl]
2023-09-29 First pass at the export feature
    [Left middle front corner.f3d]
2023-09-29 Missed a variable for the Config export
    [main.cpp]
2026-06-18 Fix AP setup disconnect, brightness reboot loop, and restore version pin
    - Reorder WiFi.softAPConfig() before WiFi.softAP() (and set WIFI_AP mode)
    so the soft-AP DHCP server hands out leases correctly; previously clients
    connected then dropped immediately and the config page was unreachable.
    - Default an empty/zero LED brightness to 100 in getPrefs() and guard the
    divide in handleLEDBreath(), fixing a divide-by-zero panic that put a
    freshly configured device into a blinking-red reboot loop (regression
    from the three-way refactor dropping the brightness field from AP setup).
    - Add a boot-time factory reset (hold reset button 3s at power-up) so a
    device stuck in a boot loop can be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
    [main.cpp]
2026-06-18 changes to allow for 3way switch setups
